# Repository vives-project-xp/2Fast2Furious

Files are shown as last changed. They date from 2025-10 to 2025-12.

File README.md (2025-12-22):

# Handgestuurde RC Wagen




> Ontwikkel een RC wagen die bestuurd wordt via handbewegingen

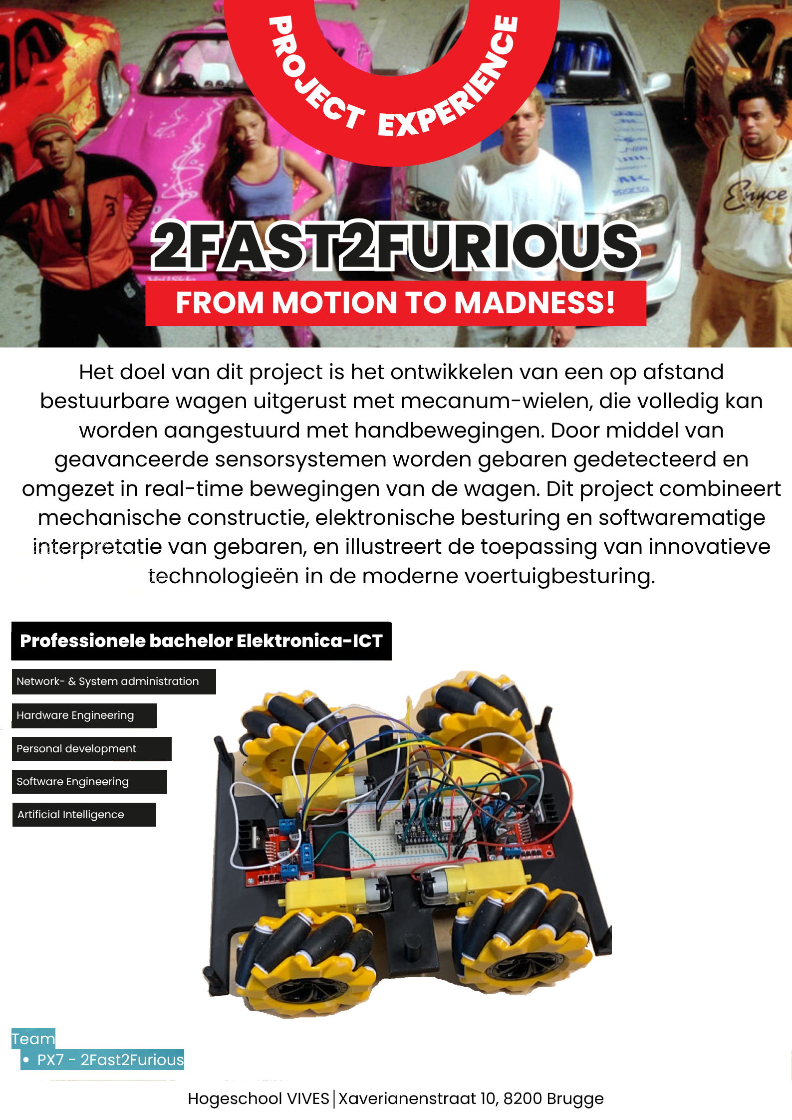
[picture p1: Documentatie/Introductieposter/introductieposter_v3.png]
Poster


## Opdracht

We ontwikkelen een RC wagen die alle richtingen uit kan rijden en bestuurd wordt via handbewegingen. De besturing van de wagen gebeurt door middel van een handcontroller die bewegingen van de hand detecteert en deze omzet in commando's voor de wagen.

## Inhoud

### Software

De software voor dit project is te vinden in de [Software](Software/README.md) map. We gebruiken Arduino C/C++ voor de ontwikkeling van de firmware voor zowel de handcontroller als de RC wagen.

### Hardware

De hardware componenten en schema's zijn te vinden in de [Hardware](Hardware/README.md) map. We maken gebruik van een microcontroller, sensoren en motoren om de RC wagen te besturen.

### Documentatie

De documentatie voor het project zijn te vinden in de [Documentatie](Documentatie/README.md) map. Hierin vind je  technische documentatie. Hierin vind je ook de uitleg over de componenten en hoe we deze hebben gebruikt in het project.

### Handleiding

De handleiding om dit project in elkaar steken en werkende te krijgen kan men vinden in de [Handleiding](Handleiding/README.md) map.

## Team

| team | Afstudeerrichting |
| ---- | --- |
| [ Sam De Wispelaere](https://github.com/SamDw123)| Software Engineering en AI |
| [ Niels Denoo](https://github.com/NielsDenoo)| Software Engineering en AI |
| [ Ewoud Bouttelisier](https://github.com/EwoudBoutje)| Software en netwerken |
| [ Maxime Coen](https://github.com/Maxime-00)| Software en netwerken |
| [ Jules Declercq](https://github.com/JulesDeclercq)| Software en netwerken |

## Planning

### Sprint 1 (week 1-4)

- [x] onderzoek naar geschikte componenten
- [x] ontwerp van de handcontroller
- [x] ontwerp van de RC wagen
- [x] testen van componenten
- [x] bestellen componenten
- [x] beginnen met code schrijven

### Sprint 2 (week 5-8)

- [x] ambassadeur van het project (poster & sociale media)
- [x] code testen en aanpassen waar nodig
- [x] in elkaar steken van de handcontroller
- [x] in elkaar steken van de RC wagen

### Sprint 3 (week 9-12)

- [X] presentatie maken
- [X] github in orde brengen
- [x] volledige tank laten rijden
- [x] ai model werkende krijgen
- [x] tank laten 'schieten' met laser transmitter
- [ ] documentatie afwerken

## Verdere uitbreidingen

- Het maken van doelwitten voor de wagon om op te schieten met het lasersysteem.

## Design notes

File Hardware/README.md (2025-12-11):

# Hardware

Deze map bevat alle hardware componenten en schema's voor het project.

## Inhoud

1. [De hardware van de auto](#de-hardware-van-de-auto)
2. [Hand Controller](#hand-controller)
3. [Tank](#tank)
3. [Target](#target)

## De hardware van de auto

### Auto

1. Arduino Nano 33 BLE Sense Rev2
2. 2x L298N motor driver
3. 4x TT-Motor
4. 7.4V Traxxas Batterij
5. Servo SG90 Micro 
6. Breadboard

### Tank gedeelte

1. Servo SG90 Micro
2. Laser Diode Transmitter

### Elektrisch schema

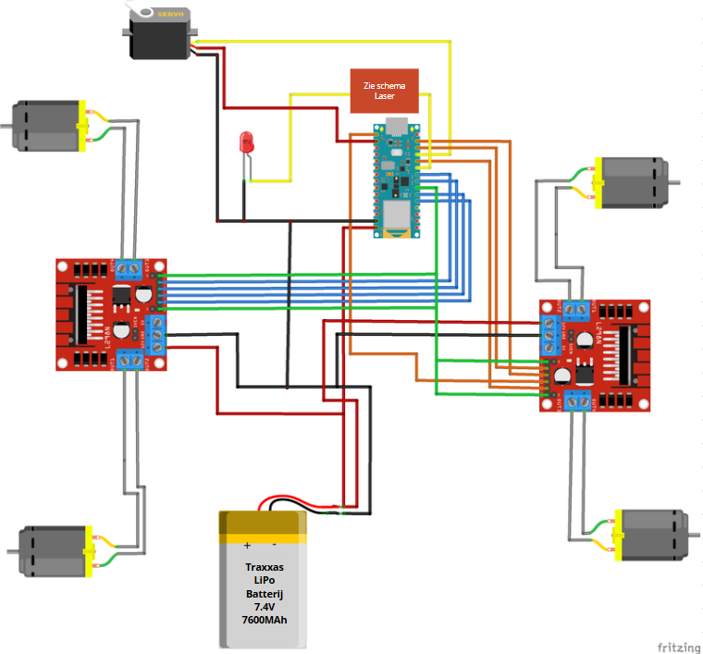
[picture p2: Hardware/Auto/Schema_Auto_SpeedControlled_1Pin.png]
schema speedcontroller


*Figuur: Elektrisch schema van de auto met Arduino Nano 33 BLE Sense REV2: Variabele snelheidsregeling*

Om bovenstaande schema na te maken moet je de twee omhulsels van de buitenste connector pinnen op de motordrivers verwijderen. Zie foto hieronder.

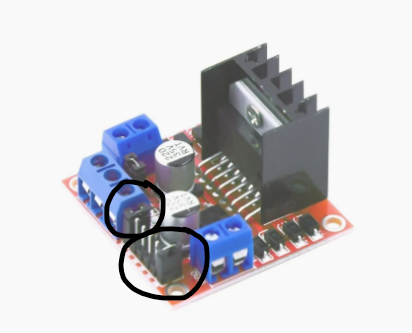
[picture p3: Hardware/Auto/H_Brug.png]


#### Variabele snelheidsregeling: 
Op het schema zijn alle motoren aangesloten op 1 snelheids regeling Pin. Dit zorgt er voor dat je alle motoren samen kunt versnellen of vertragen. Dit word bij ons gebruikt om in "tank mode" rond te draaien zodat de tank niet te snel draait en in de "car mode" om de snelhied iets te berpeken tijdens het rijden.

### Schema Laser 

Helaas stuurt de Arduino Nano 33 BLE Rev2 maar 3,3V signaalen uit en heeft de laser zelf 5V nodig. Met 3,3V is deze laser niet fel genoeg. Hiervoor moesten we nog een schakeling voorzien.

Deze schakeling bestaat uit volgende onderdelen:
1. HW-493 Laser board
2. BD135 NPN Transistor
3. 220 Ohm weerstand
4. 3xAAA batterijhouder

De drie AAA-batterijen (4,5 V) voeden de laser zodat deze feller is. De Arduino gebruikt de transistor als een digitale schakelaar om deze laser AAN en UIT te zetten.

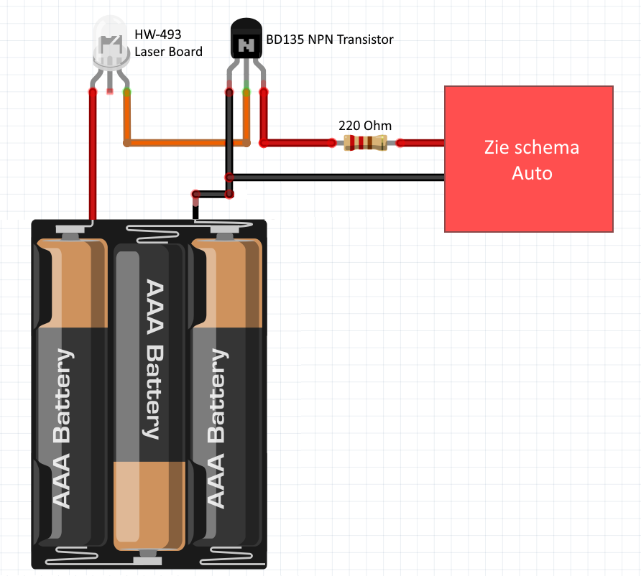
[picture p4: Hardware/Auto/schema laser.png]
schema laser


## Hand Controller

### Concept

De hand controller is de intuïtieve/immersive interface voor de besturing van de RC-car, met uitbreiding van een turret.

### Kern

De controller maakt gebruik van een Arduino Nano 33 BLE Sense Rev2. Deze microcontroller werd gekozen vanwege:

1. Inertial Measurement Unit (IMU): De interne accelerometer en gyroscoop lezen de pitch (voor/achterwaartse kanteling) en de roll (zijwaartse kanteling) data om de oriëntatie van de hand in real-time te bepalen.
2. Bluetooth Low Energy (BLE) Module: Voor draadloze communicatie met de RC-car.
3. Magic Wand/Tensorflow Gesture Recognition als uitbreiding. Laat toe te schakelen tussen verschillende modussen of functies van de controller zonder extra knoppen te monteren/de andere hand te moeten gebruiken.

### Montage

De Arduino wordt gemonteerd op een 3D-geprintte palm-bracelet dat ook de 3x AAA batterijhouder power supply huist. Zie de .stl-files voor meer info.

### Besturing

De bewegingsdata van de IMU wordt in onze software vertaald naar digitale bewegingscommando's en verzonden naar de RC-car.

| Modus | IMU Data | Commando |
| :--- | :--- | :--- |
| Car | Kantelen naar voren | Rijden vooruit |
| Car | Kantelen naar achteren | Rijden achteruit |
| Car | Kantelen naar links | Rijden links |
| Car | Kantelen naar rechts | Rijden rechts |
| Car | Kantelen naar linksvoor | Rijden linksvoor in hondengang |
| Car | Kantelen naar rechtsvoor | Rijden rechtsvoor in hondengang |
| Car | Kantelen naar linksachter | Rijden linksachter in hondengang |
| Car | Kantelen naar rechtsachter | Rijden rechtsachter in hondengang |
| Turret | Kantelen naar links | Car roteert op as links |
| Turret | Kantelen naar rechts | Car roteert op as rechts |
| Turret | Kantelen naar voren | Turret mikt hoger (servo) |
| Turret | Kantelen naar achteren | Turret mikt lager (servo) |

### Turret Modus

Aan de hand van Gesture Recognition kan de user schakelen tussen verschillende modussen.
In Turret Modus veranderd de interpretatie van de IMU-data:

Zijwaartse kanteling wordt gebruikt om de car op zijn vaste as te laten roteren, zoals in tank-besturing.
De voor- en achterwaartse kanteling wordt gebruikt om een servomotor in de turret aan te sturen. Deze servo is verantwoordelijk voor de elevatie van een gemonteerde laserdiode.

### Laserdiode

De eerdervernoemde Gesture Recognition die zorgt voor schakelen tussen de twee modussen en heeft een secundaire functie, namelijk de laserdiode aan of uit schakelen.
De 'Gesture' die men daarvoor moet doen is een 'punch' of met andere woorden een stoot geven met de vuist.
Dit voorkomt dat de laser onbedoeld aanblijft.

### Onderdelen Hand controller
1. Arduino Nano 33 BLE Sense REV2

2. 3xAAA batterijhouder

3. Bracelet behuizing en straps

#### Schema:

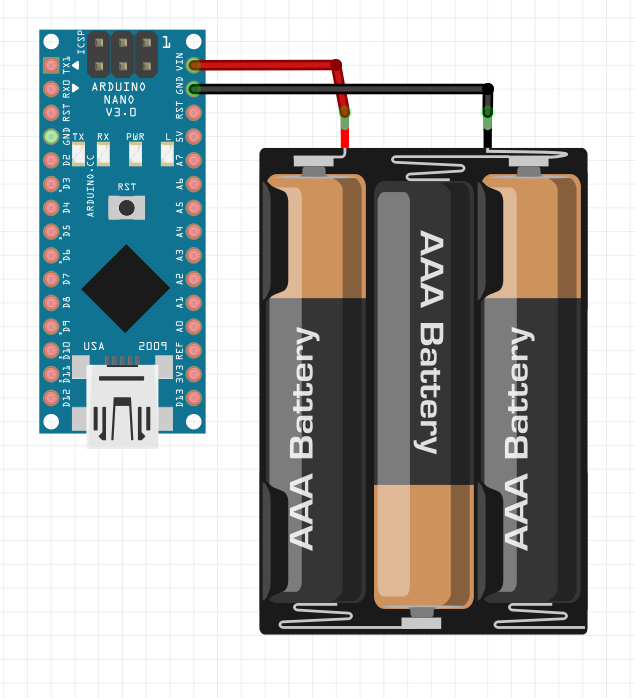
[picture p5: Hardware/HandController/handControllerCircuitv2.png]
Schema van de hand controller


### STL

Alle STL files voor het ontwerp van de handcontroller die gebruikt werden tijdens dit project zijn te vinden in deze [map](./Handschoen/STL_files/).

## Tank

### Previews

De RC tank is gemaakt uit vier verschillende onderdelen, zijnde het chassis van de tank, de carosserie, de kop en een loop. 

Het chassis is gedesigned zodat er plaats voorzien is voor de vier motoren, alsook plaats voor twee driver boards. Verder zijn er kleine pinnen voorzien op het chassis zodat de carosserie er op bevestigd kan worden.

Op de bovenkant van de carosserie is er plaats voorzien voor de servo-motor met ook een gat voor bekabeling. Daarnaast zijn er gaten aan de onderkant zodat de carosserie op het chassis past. Aan de bovenkant zijn er gaten voorzien voor het bevestigen van de kop.

In de kop is er een gat voorzien om de loop door te steken.
Ook zijn er pinnen voorzien aan de onderkant voor de montage op de carosserie.

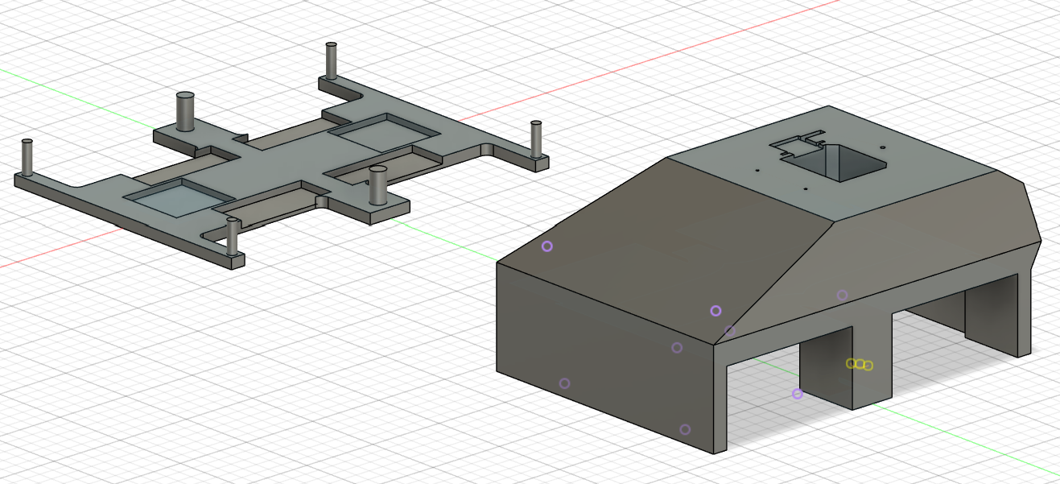
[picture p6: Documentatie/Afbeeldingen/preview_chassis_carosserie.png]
chassis

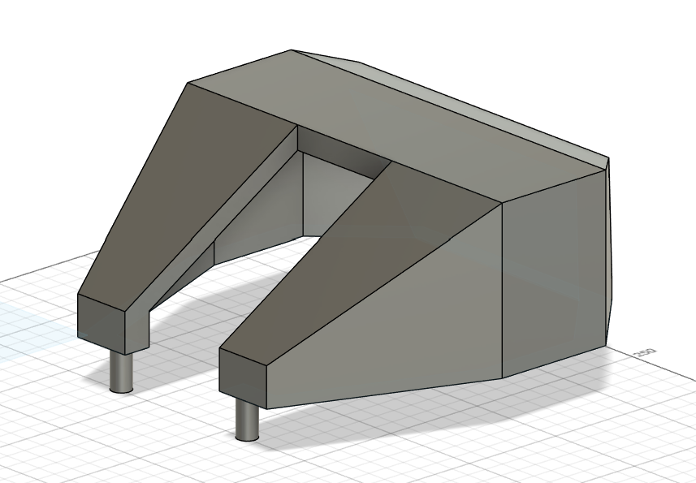
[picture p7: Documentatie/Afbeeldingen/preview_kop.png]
kop

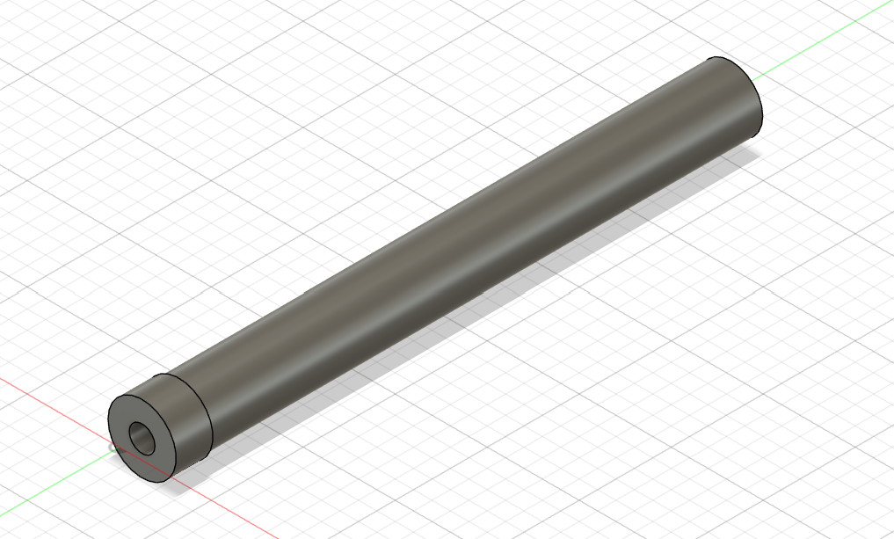
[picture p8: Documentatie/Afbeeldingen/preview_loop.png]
loop


### STL

Alle STL files voor het ontwerp van de tank die gebruikt werden tijdens dit project zijn te vinden in deze [map](./Tank/STL_files/).

⬅️ [Terug naar overzicht](../README.md#Inhoud)

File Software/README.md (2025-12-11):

# Software

In deze map bevindt zich alle **broncode** die ontwikkeld is voor dit project.

## Bestandsstructuur

De code is georganiseerd in de volgende hoofdmappen om het beheer en de testbaarheid te optimaliseren:

* **`MainCode/`**: Bevat de **volledige, definitieve broncode** voor de productieversie van de robot.
    * `SpeedControlledCar.ino`: Code voor de **robotwagen** met speed controlled auto. (geupload naar de Arduino op de auto).
    * `gesture_classifier.ino`: Code voor de **handcontroller** met gestures als **Circle** en **Punch** om van mode te switchen en te "schieten". [Voor meer info hier over klik hier](./MainCode/gestureModel/README.md) .

* **`Test Codes/`**: Bevat diverse **losse scripts** die zijn geschreven om specifieke hardware- of software-onderdelen onafhankelijk te testen, zoals de BLE-verbinding, motoraansturing of sensordata-uitlezing.

## Gebruikte Libraries

De meeste programma's maken gebruik van standaard Arduino-libraries. Hieronder vind je een overzicht van de belangrijkste:

| Library | Functie |
| :--- | :--- |
| `ArduinoBLE.h` | Voor het opzetten en beheren van de Bluetooth Low Energy (BLE) verbinding. |
| `Servo.h` | Voor het eenvoudig aansturen van de servomotor. |
| `Arduino_BMI270_BMM150.h` | Voor het uitlezen van sensor- en gyroscoopdata. |
| `Chirale_TensorFlowLite.h` | Voor de gesture classifier. |

## Uploaden & Setup

Om de code te uploaden en het project te kunnen draaien, volgt u de onderstaande stappen:

1. **Arduino IDE Installeren:** Zorg ervoor dat de nieuwste versie van de **Arduino IDE** is geïnstalleerd.
2. **Libraries Installeren:** Installeer de libraries die vermeld staan in de tabel (via **Sketch > Library's Inclusief > Library's Beheren...** in de IDE).
3. **Uploaden naar de Auto:** Open het **`SpeedControlledCar.ino`** bestand en upload deze code naar de Arduino die is gemonteerd op de **robotwagen**.
4. **Uploaden naar de Controller:** [Voor meer info hier over klik hier](./MainCode/gestureModel/README.md).

>**Tip:** Zorg ervoor dat in de Arduino IDE het juiste **Board** en de juiste **Poort** zijn geselecteerd voordat u de code uploadt.

---

⬅️ [Terug naar overzicht](../README.md#Inhoud)

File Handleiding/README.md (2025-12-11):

# Handleiding

Hier kan je een handleiding vinden voor het in elkaar steken en werkende te krijgen van de tank.

## tank bouwen

Maak eerst de tank volgens het elektrische schema in de map [hardware](../Hardware/README.md).

Elektrisch schema tank

Bevestig daarna alle onderdelen op de grondplaat van de tank. De stl files voor deze af te printen vind je in de map [hardware/tank/STL_files](../Hardware/Tank/STL_files/README.md).

## Software installeren op de tank

Op de microcontroller van de tank moet je [speedcontrolledcar.ino](../Software/MainCode/SpeedControlledCar/SpeedControlledCar.ino) uploaden. Dit kan je doen met de Arduino IDE.

Zorg dat je de juiste board en poort selecteert in de Arduino IDE voordat je upload en ook dat je de benodigde libraries hebt geïnstalleerd.
De benodigde libraries zijn:

- Servo
- ArduinoBLE

## Software installeren op de controller

Op de microcontroller van de controller moet je [gesture_classifier.ino](../Software/MainCode/handcontroller/gesture_classifier/gesture_classifier.ino) uploaden. Dit kan je doen met de Arduino IDE.
Zorg dat je de juiste board en poort selecteert in de Arduino IDE voordat je upload en ook dat je de benodigde libraries hebt geïnstalleerd.
De benodigde libraries zijn:

- ArduinoBLE
- Arduino_BMI270_BMM150
- Chirale_TensorFlowLite

Zorg er ook voor dat het model bestand `gesture_model.h` in dezelfde map staat als `gesture_classifier.ino`.

## handcontroller bouwen

Maak de handcontroller volgens het elektrische schema in de map [hardware](../Hardware/README.md).

Elektrisch schema handcontroller

Bevestig daarna alle onderdelen op de handschoen. De stl files voor deze af te printen vind je in de map [hardware/handschoen/STL_files](../Hardware/HandController/STL_files/README.md).

## model maken

Om een nieuw model te maken voor de handcontroller, volg de stappen in de map [gestureModel](../Software/MainCode/gestureModel/README.md). Daar wordt uitgelegd hoe je een nieuw model kan trainen en exporteren naar een bestand dat je kan gebruiken in de Arduino IDE.

## Verbinden en gebruiken

Zorg dat de tank en de controller beide aanstaan. De controller zal automatisch verbinding maken met de tank zodra deze binnen bereik is. De connectie kun je zien in de seriële monitor van de Arduino IDE of putty op baudrate 115200. Zodra de verbinding is gemaakt, kun je de tank besturen met gebaren en handbewegingen. Als hij geen verbinding maakt, reset de controller op de tank.

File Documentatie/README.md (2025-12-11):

# Documentation

Deze map bevat documentatie en specificaties voor het project.

## BOM

Hieronder staat de Bill of Materials (BOM) voor het project:

| Component | Prijs/stuk | Aantal | Totaalprijs | Opmerking | Link naar component |
|---|---|---|---|---|---|
| Arduino Nano 33 BLE Sense Rev2 with Headers | €44,15 | 2 | €88,30 | Microcontroller met gyroscoop en bluetooth | [kiwi](https://www.kiwi-electronics.com/en/arduino-nano-33-ble-sense-rev2-with-headers-11207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) |
| mecanum wielen (2 stuks) | €13,00 | 2 | €26,00 | Wielen voor omnidirectionele beweging | [otronic](https://www.otronic.nl/nl/mecanum-wiel-omnidirectioneel-wiel-80mm-a-geel-set.html) |
| McNamum wielkoppeling | €4,40 | 4 | €17,60 | Koppeling voor mecanum wielen | [otronic](https://www.otronic.nl/nl/67mm-mcnamum-wielkoppeling-met-m2530-schroef.html) |
| TT-motor | €2,00 | 4 | €8,00 | Motor voor aandrijving van de wielen | [otronic](https://www.otronic.nl/nl/tt-motor-voor-aandrijving-wielen-dubbele-as.html) |
| L298N motor driver | €2,60 | 2 | €5,20 | Motor driver voor het aansturen van de TT-motoren | [otronic](https://www.otronic.nl/nl/l298n-motor-driver-board-rood.html) |
| 4,5V batterij houder | €0,85 | 2 | €1,70 | Batterijhouder voor 3 AAA batterijen (4,5V) | [otronic](https://www.otronic.nl/nl/3x-aaa-batterijhouder-45v.html) |
| 7.4V Traxxas Batterij | €84,95 | 1 | €84,95 | Batterij voor de auto | [bol.com](https://www.bol.com/nl/nl/p/traxxas-lipo-accupack-7-4-v-7600-mah-aantal-cellen-2-25-c-softcase-traxxas-id/9200000058970910/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) |
| Aansluit kabel batterij | €9,95 | 1 | €9,95 | Connector kabel voor batterij | [bol.com](https://www.bol.com/nl/nl/p/laadkabel-traxxas-30cm/9300000013705973/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) |
| servomotor SG90 micro | €4,15 | 1 | €4,15 | Servomotor voor kanon op en neer | [otronic](https://www.otronic.nl/nl/servo-sg90-micro-180-graden.html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) |
| lasertransmitter | €1,20 | 1 | €1,20 | Lasertransmitter voor kanon | [otronic](https://www.otronic.nl/nl/laser-diode-5v-module-rode-laser-650nm-5mw-koperen.html) |
| laser ontvanger | €1,95 | 1 | €1,95 | Laser ontvanger voor target | [otronic](https://www.otronic.nl/nl/5v-ontvanger-module-voor-laser-diode.html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) |
| arduino nano | €6,80 | 1 | €6,80 | Microcontroller voor de target | [otronic](https://www.otronic.nl/nl/nano-v3-arduino-compatible-ch340-voorgesoldeerd.html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) |
| PLA filament | €22,99 | 2 | €45,98 | Voor het 3D printen | [bambu](https://eu.store.bambulab.com/nl/products/pla-basic-filament?id=43992830017755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) |

De totaalprijs van alle componenten is: €301,78
   
## Componenten

Hieronder wat meer informatie over de gebruikte componenten:

### Arduino Nano 33 BLE Sense Rev2 with Headers

De Arduino Nano 33 BLE Sense Rev2 is een compacte  microcontroller vergelijkbaar met de standaard Arduino Nano, maar met extra functionaliteit. De microcontroller bevat een ingebouwde gyroscoop dat we gebruiken voor de bewegingsdetectie van de handcontroller. Daarnaast heeft de microcontroller bluetooth functionaliteit waarmee we draadloos kunnen communiceren tussen de handcontroller en de auto.

### TT-motor

De TT-motor is een kleine, goedkope en efficiënte motor die vaak wordt gebruikt in robotica en kleine voertuigen. In ons project gebruiken we de TT-motoren om de mecanum wielen aan te drijven.

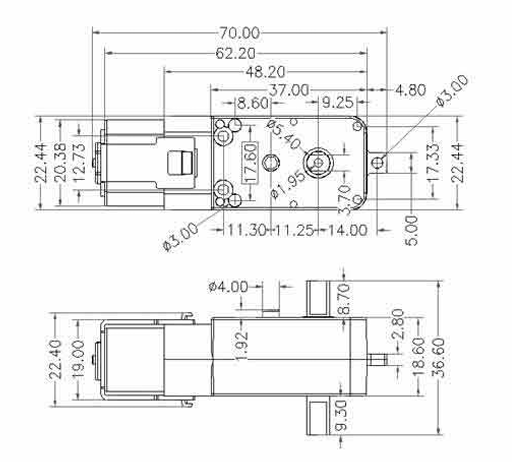
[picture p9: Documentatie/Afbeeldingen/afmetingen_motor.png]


### L298N motor driver

De L298N motor driver is een motor driver die we gebruiken om de TT-motoren aan te sturen. De motor driver kan twee DC-motoren tegelijk aansturen en kan zowel de snelheid als de draairichting van de motoren regelen.

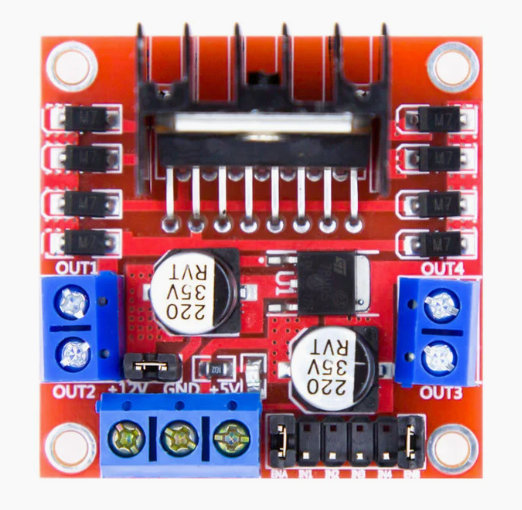
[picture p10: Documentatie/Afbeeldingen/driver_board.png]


### Mecanum wielen

Mecanum wielen zijn speciale wielen die omnidirectionele beweging mogelijk maken. Dit betekent dat het voertuig in elke richting kan bewegen zonder van richting te veranderen. Dit wordt bereikt door de unieke constructie van de wielen, die bestaan uit meerdere rollers die onder een hoek zijn geplaatst.

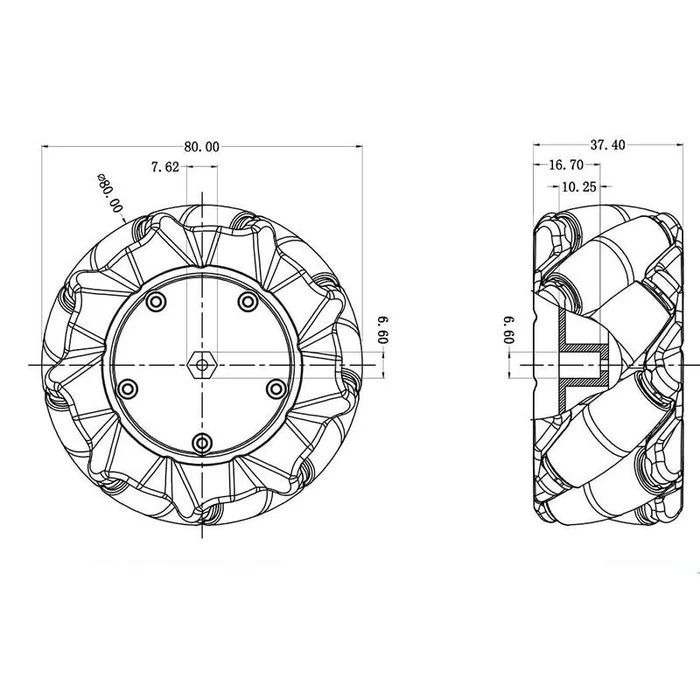
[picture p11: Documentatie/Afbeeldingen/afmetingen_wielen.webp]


### Servomotor SG90 micro

De SG90 is een kleine en lichte servomotor die vaak wordt gebruikt in modelbouw en robotica. In ons project gebruiken we de SG90 servomotor om het kanon van de auto omhoog en omlaag te bewegen.

### Lasertransmitter en ontvanger

De lasertransmitter zendt een laserstraal uit die wordt gebruikt als projectiel in ons lasershooterspel. De laser ontvanger detecteert wanneer de laserstraal wordt geraakt, wat wordt gebruikt om te bepalen of een doelwit is getroffen.

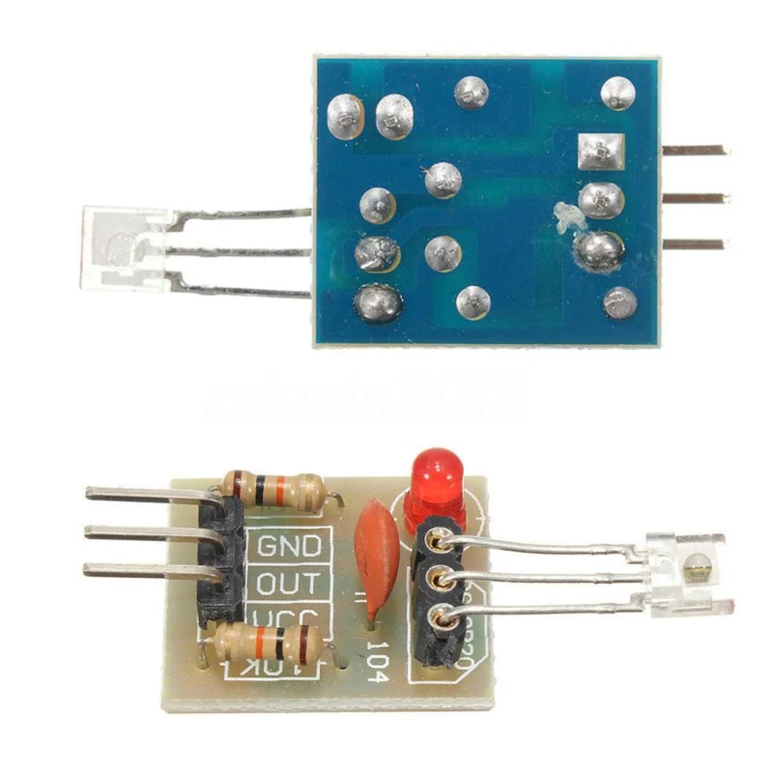
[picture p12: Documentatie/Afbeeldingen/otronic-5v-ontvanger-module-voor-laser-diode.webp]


### Arduino nano

De Arduino Nano is een kleine, veelzijdige microcontroller die we gebruiken in de target van ons lasershooterspel. Het is verantwoordelijk voor het detecteren van hits van de laserstraal en het bijhouden van de score.

## Idee kanon en target

### Kanon

Het idee dat we hebben voor het kanon is om een servomotor op de tank te plaatsen die het kanon omhoog en omlaag kan bewegen. Op het kanon is een lasertransmitter gemonteerd die een laserstraal uitzendt wanneer het kanon wordt afgevuurd. De lasertransmitter wordt aangestuurd door de Arduino Nano 33 BLE Sense Rev2 op de handcontroller en de servomotor ook. De besturing via de handcontroller zou nog steeds hetzelfde zijn maar we voegen een extra knop toe om te wisselen tussen rijden en turret modus. In turret modus kan de gebruiker het kanon omhoog en omlaag bewegen met behulp van de gyroscoop in de handcontroller, ook kan de gebruiker de tank laten draaien rond zijn eigen as. De laser gaat aan zodra de wagen in turret modus wordt geschakelt.

### Target

Het target bestaat uit een Arduino Nano die is verbonden met een laser ontvanger module. De laser ontvanger detecteert wanneer de laserstraal van het kanon het target raakt. Wanneer een hit wordt gedetecteerd, stuurt de Arduino Nano een signaal naar een LED of een buzzer om aan te geven dat het target is geraakt. Daarnaast kan de Arduino Nano ook de score bijhouden en deze weergeven op een klein LCD-scherm.

## Introductieposter

[Hier](./Introductieposter/introductieposter.md) kan je de introductieposter vinden van ons project.

## Architectuur document

Hieronder staan de architectuur documenten voor het project.

### Architectuur van de auto

Architectuur van de auto

### Architectuur van de handcontroller

Architectuur van de handcontroller  

## Prototypes

In de map [afbeeldingen](./Afbeeldingen/) kan je enkele foto's vinden van enkele prototype's. Er is een afbeelding te vinden van een amazon variant waar onze eigen rc wagen op gebaseerd is. Er zijn ook schetsen te vinden over hoe we componenten plaatsen op onze rc wagen (ook te afmetingen zijn hierop te vinden). Verder zijn er afbeeldingen te vinden genaamd 3d_tank en 3d_handcontroller, deze tonen eerdere versies van de uiteindelijke tank en handcontroller.

⬅️ [Terug naar overzicht](../README.md#Inhoud)

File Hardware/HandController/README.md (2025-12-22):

# Handcontroller

De hand controller bestaat uit twee onderdelen: fysiek en elektronica.

## Fysiek

Het fysiek onderdeel bestaat uit vijf componenten: 
- Housing bodemplaat (gehold)
- Housing bovenplaat (gehaakt)
- Housing arduino gleuf
- Pols strap (gaten)
- Pols strap (haken)

De housing-componenten kunnen worden afgeprint a.d.h.v. de .stl-files, gevonden in de submap van de huidige folder.
De pols straps zijn gerecycleerd uit de hand controller van een chinees speelgoed autotje gedoneerd door Mnr. Calleeuw.

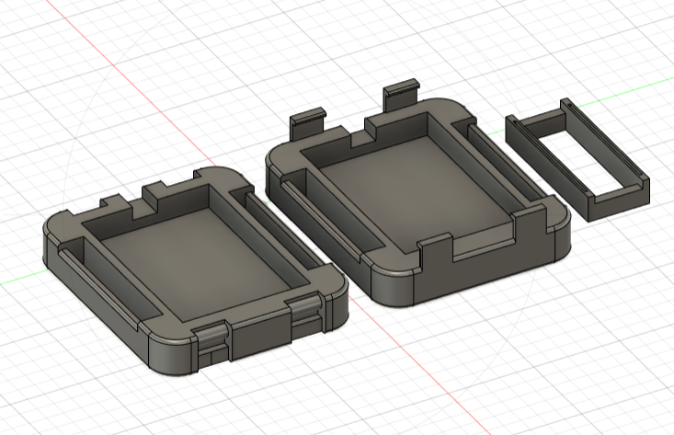
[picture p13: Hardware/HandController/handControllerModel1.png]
Hand Controller Fysieke Onderdelen


## Elektronica

Het elektronica onderdeel bestaat uit drie componenten:
- Microcontroller Arduino Nano 3.3V BLE
- 3xAAA batterijhouder (incl. 3xAAA batterijen)
- Luskoppen voor elektrische draden

## Assemblage

De binnenkant van de twee housing platen beschikken over een holte waarin de 3xAAA batterijhouder past, alsook een zijdelingse holte waardoor de bedrading van de batterijhouder kan worden gestoken om uit de housing te geraken. Bemerkt dat de bovenplaat extra plaats overhoudt in de holte voor de draden, terwijl de bodemplaat dat niet doet om de batterijhouder vanbinnen vast te houden.

> Plaats de batterijhouder met batterijen in de holte van de bodemplaat, met de bedrading door de zijdelingse holte.

Aan de lange zijdes van de platen zijn gleuven voorzien voor de koppen van de pols straps. Afhankelijk van of de gebruiker zijn of haar linker- of rechterhand wild gebruiken, kunnen deze straps omgewisseld worden.

> Plaats de koppen van de pols straps in de gleuven.

> Klik de bovenplaat vast in de bodemplaat om de batterijhouder en pols straps vast te zetten. Extra aandacht dat de bedrading niet dubbel komt te zitten.

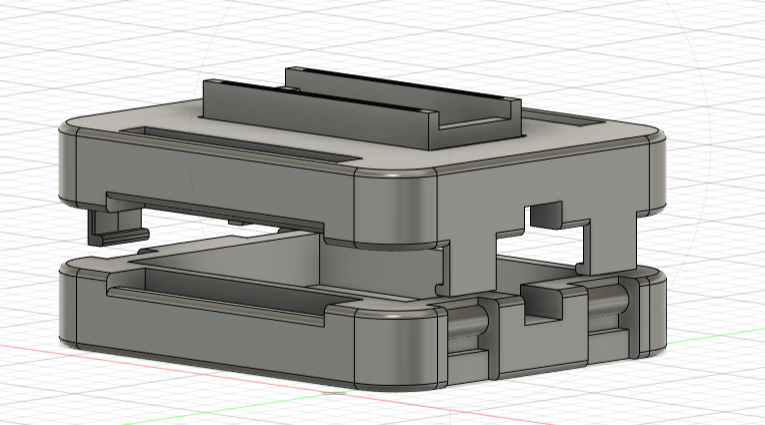
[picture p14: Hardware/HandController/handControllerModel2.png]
Hand Controller Fysieke Onderdelen


Bovenop de bovenplaat is er een holte voorzien voor de arduino gleuf.

> Plaats de arduino gleuf in de holte op de bovenplaat en zet deze vast met lijm. Extra aandacht de gleuven niet te buigen.

De luskoppen voor de bedrading dienen voor gemakkelijke vastmaking op de corresponderende pinnen op de arduino, zie hier: [Hand Controller Fysieke Onderdelen](handControllerCircuitv2.png)

> Voorzie de bedarding van luskoppen, en maak deze vast aan de juiste pinnen van de arduino.

> Schuif de arduino in de gleuf zodat de luskoppen vast komen te zitten tussen de arduino en de gleuf. Extra aandacht dat de arduino goed vastzit in de gleuf.

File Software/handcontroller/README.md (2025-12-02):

# De software van de handschoen

Deze map bevat alle software die op de Arduino Nano 33 BLE Sense Rev2 van de handschoen draait.

## Bestanden

- `gesture_classifier.ino`: Dit is het hoofdprogramma dat de sensorgegevens leest, gebarenclassificatie uitvoert en de resultaten verzendt via Bluetooth. Deze map bevindt zich in de gesture_classifier map.

## Vereisten

**Arduino Bibliotheken**:

   - `Chirale_TensorFlowLite`
   - `Arduino_BMI270_BMM150`
   - `ArduinoBLE`

**model toevoegen**
Het model `gesture_model.h` moet zich in dezelfde map bevinden als `gesture_classifier.ino`.

## Gebruik

1. Open `gesture_classifier.ino` in de Arduino IDE.
2. Zorg ervoor dat alle vereiste bibliotheken zijn geïnstalleerd.
3. Upload de code naar de Arduino Nano 33 BLE Sense Rev2.
4. Koppel de handschoen via Bluetooth aan met de ontvanger (tank). Dit zal automatisch gebeuren zodra de tank en de handschoen worden ingeschakeld.
5. Open een seriële monitor (baudrate 115200) om debug-informatie te bekijken.

## Uitleg van de code

### Overzicht
De `gesture_classifier.ino` code combineert IMU-sensordata met machine learning om handgebaren te herkennen en te classificeren. De code werkt non-blocking, wat betekent dat het geen gebruik maakt van `delay()` functies die het programma blokkeren, waardoor BLE-communicatie en andere taken soepel blijven verlopen.

### Hoofdcomponenten

#### 1. Globale Configuratie en Constanten
```cpp
const int NUM_SAMPLES = 200;      // Aantal samples per gebaar
const int NUM_AXES = 6;           // 3 accelerometer + 3 gyroscoop assen
const int NUM_FEATURES = 24;      // 4 statistieken per as (mean, std, min, max)
const int NUM_CLASSES = 3;        // Aantal gebaar-klassen
```
- **NUM_SAMPLES**: Er worden 200 datapunten verzameld voordat een gebaar wordt geclassificeerd
- **NUM_AXES**: 6 dimensies van bewegingsdata (X, Y, Z voor acceleratie en rotatie)
- **NUM_FEATURES**: Per as worden 4 statistieken berekend (gemiddelde, standaarddeviatie, minimum, maximum)
- **GESTURES[]**: Array met de namen van de gebaren: "Punch", "circle" en "idle"

#### 2. TensorFlow Lite Setup
```cpp
constexpr int kTensorArenaSize = 12 * 1024;  // 12KB voor TensorFlow
alignas(16) uint8_t tensor_arena[kTensorArenaSize];
```
De TensorFlow Lite interpreter heeft geheugen nodig om het neural network model uit te voeren. Dit wordt gereserveerd in de `tensor_arena` buffer van 12KB.

#### 3. Data Opslag en Sampling
```cpp
int16_t sample_buffer[NUM_SAMPLES][NUM_AXES];
```
De sensordata wordt opgeslagen als 16-bit integers om geheugen te besparen:
- **Acceleratie**: opgeslagen als milli-g (waarde × 1000)
- **Gyroscoop**: opgeslagen als centi-graden/sec (waarde × 100)

Dit bespaart 50% geheugen vergeleken met 32-bit floats, wat cruciaal is op een microcontroller.

#### 4. Non-Blocking Sampling State Machine
```cpp
bool samplingActive = false;
unsigned long nextSampleMs = 0;
const unsigned long sampleIntervalMs = 10;        // 10ms tussen samples
const unsigned long cycleCooldownMs = 500;        // 500ms pauze na detectie
```
De code gebruikt een state machine met tijdstempels om non-blocking te werken:
- Samples worden elke 10ms genomen (100 Hz)
- Na detectie van een gebaar volgt een cooldown van 500ms
- Dit voorkomt dat dezelfde beweging meerdere keren wordt gedetecteerd

#### 5. Preprocessing Parameters
```cpp
const float feature_mean[NUM_FEATURES] = { ... };
const float feature_std[NUM_FEATURES] = { ... };
```
Deze arrays bevatten de normalisatieparameters die tijdens het trainen van het model zijn berekend. Ze worden gebruikt om de features te standaardiseren (zero mean, unit variance), wat essentieel is voor accurate classificatie.

### Setup() Functie

De `setup()` functie initialiseert alle componenten:

1. **IMU Initialisatie**
   ```cpp
   if (!IMU.begin()) {
     Serial.println("ERROR: IMU initialization failed!");
     while (1);
   }
   ```
   Start de BMI270/BMM150 sensor en controleert of deze correct werkt.

2. **BLE Setup**
   ```cpp
   BLE.setLocalName("NanoClassifier");
   BLE.setAdvertisedService(controlService);
   ```
   Configureert Bluetooth Low Energy met de naam "NanoClassifier" en maakt een service aan met UUID `12345678-1234-5678-1234-56789abcdef0`.

3. **TensorFlow Lite Model Laden**
   ```cpp
   model = tflite::GetModel(gesture_model);
   static tflite::MicroInterpreter static_interpreter(...);
   ```
   Laadt het getrainde model uit `gesture_model.h` en initialiseert de TensorFlow Lite interpreter.

### Loop() Functie - Hoofdlogica

De `loop()` functie doorloopt continu verschillende fases:

#### Fase 1: BLE Polling en Connectie Management
```cpp
BLE.poll();
if (BLE.connected() && !deviceConnected) {
  Serial.println("BLE connected");
  deviceConnected = true;
}
```
Houdt de BLE-verbinding actief en detecteert wanneer een apparaat verbindt/disconnecteert.

#### Fase 2: Start van Sampling Cyclus
```cpp
if (!samplingActive && now >= nextCycleMs) {
  samplingActive = true;
  samples_read = 0;
  nextSampleMs = now;
}
```
Start een nieuwe sampling cyclus wanneer:
- Er momenteel geen sampling actief is
- De cooldown periode is verlopen

#### Fase 3: Data Acquisitie
```cpp
if (samplingActive && now >= nextSampleMs) {
  if (IMU.accelerationAvailable()) {
    IMU.readAcceleration(aX, aY, aZ);
    IMU.readGyroscope(gX, gY, gZ);
    
    // Opslaan in buffer als int16_t
    sample_buffer[samples_read][0] = (int16_t)(aX * 1000.0f);
    // ... etc voor andere assen
  }
}
```
Leest IMU-data wanneer beschikbaar en slaat deze compact op in de sample buffer.

#### Fase 4: Realtime Bewegingscommando's
```cpp
if ((samples_read % LOG_INTERVAL) == 0 && lastDetectedIsIdle) {
  String cmd = getCommand(xi, yi);
  Serial.println(cmd);
  commandCharacteristic.writeValue(cmd);
}
```
Tijdens het verzamelen van samples worden bewegingsrichtingen berekend op basis van de acceleratiedata:
- **F**: Forward (vooruit)
- **B**: Backward (achteruit)
- **L**: Left (links)
- **R**: Right (rechts)
- **FL, FR, BL, BR**: Diagonale richtingen
- **S**: Stop (stilstand)

Deze commando's worden alleen verstuurd wanneer het laatste gedetecteerde gebaar "idle" was, om interferentie met gebaar-detectie te voorkomen.

#### Fase 5: Feature Extraction
```cpp
void extractFeatures(float features[NUM_FEATURES]) {
  for (int axis = 0; axis < NUM_AXES; axis++) {
    // Bereken mean, std, min, max voor elke as
    float mean = sum / NUM_SAMPLES;
    float std_dev = sqrt(variance);
    features[base_idx + 0] = mean;
    features[base_idx + 1] = std_dev;
    features[base_idx + 2] = min_val;
    features[base_idx + 3] = max_val;
  }
}
```
Voor elke van de 6 assen worden 4 statistische kenmerken berekend:
- **Gemiddelde**: centrale tendentie van de beweging
- **Standaarddeviatie**: variabiliteit/intensiteit van de beweging
- **Minimum**: extreme waarde in negatieve richting
- **Maximum**: extreme waarde in positieve richting

Dit resulteert in 24 features (6 assen × 4 statistieken).

#### Fase 6: Feature Normalisatie
```cpp
void normalizeFeatures(float features[NUM_FEATURES]) {
  for (int i = 0; i < NUM_FEATURES; i++) {
    features[i] = (features[i] - feature_mean[i]) / feature_std[i];
  }
}
```
Standaardiseert alle features naar gemiddelde 0 en standaarddeviatie 1. Dit is cruciaal omdat:
- Het neural network verwacht genormaliseerde input
- Het voorkomt dat features met grotere waarden domineren
- Het verbetert de trainingssnelheid en nauwkeurigheid

#### Fase 7: Neural Network Inferentie
```cpp
for (int i = 0; i < NUM_FEATURES; i++) {
  input->data.f[i] = features[i];
}
interpreter->Invoke();
```
De genormaliseerde features worden naar de input tensor van het model gekopieerd, waarna `Invoke()` het neural network uitvoert en voorspellingen genereert.

#### Fase 8: Classificatie en Output
```cpp
float max_score = output->data.f[0];
int max_index = 0;
for (int i = 1; i < NUM_CLASSES; i++) {
  if (output->data.f[i] > max_score) {
    max_score = output->data.f[i];
    max_index = i;
  }
}
```
Het model output bevat een confidence score voor elke klasse. De klasse met de hoogste score wordt geselecteerd:
- **Index 0 (Punch)**: Stuurt commando "P"
- **Index 1 (Circle)**: Stuurt commando "C"
- **Index 2 (Idle)**: Geen speciale actie, activeert bewegingscommando's

#### Fase 9: Cooldown en State Reset
```cpp
samples_read = 0;
samplingActive = false;
lastDetectedIsIdle = (max_index == 2);
nextCycleMs = millis() + cycleCooldownMs;
```
Na classificatie wordt de state gereset en begint een cooldown periode van 500ms voordat de volgende detectiecyclus start.

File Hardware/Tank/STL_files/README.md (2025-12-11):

# STL files tank

In deze map kan je de STL files vinden om de onderdelen van de tank te 3D printen.

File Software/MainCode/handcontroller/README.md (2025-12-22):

# De software van de handschoen

Deze map bevat alle software die op de Arduino Nano 33 BLE Sense Rev2 van de handschoen draait.

## Bestanden

- `gesture_classifier.ino`: Dit is het hoofdprogramma dat de sensorgegevens leest, gebarenclassificatie uitvoert en de resultaten verzendt via Bluetooth. Deze map bevindt zich in de gesture_classifier map.
- gesture_model.h: Dit bestand bevat het getrainde TensorFlow Lite model dat wordt gebruikt voor gebarenherkenning. Dit bestand moet worden gegenereerd door het trainingsproces en in dezelfde map als `gesture_classifier.ino` worden geplaatst. Het trainen bevindt zich in de [gesture_classifier](../gesture_classifier/README.md) map.

## Vereisten

**Arduino Bibliotheken**:

- `Chirale_TensorFlowLite`
- `Arduino_BMI270_BMM150`
- `ArduinoBLE`

**Model**
Het model `gesture_model.h` moet zich in dezelfde map bevinden als `gesture_classifier.ino`.

## Gebruik

1. je maakt een .venv aan:

```bash
python -m venv .venv
.venv\Scripts\activate   
# Op Linux gebruik je: source .venv/bin/activate
```

2. Installeer de benodigde packages:

```bash
pip install -r requirements.txt
```

3. Installeer arduino libraries in arduino IDE of via Arduino CLI:

    **Arduino IDE**:
    Installeer volgende libraries in de Arduino IDE via Library Manager (Sketch -> Include Library -> Manage Libraries...):

    - Arduino_BMI270_BMM150
    - Chirale_TensorFlowLite

    **Arduino CLI**:

   - Download Arduino CLI van [arduino.cc/en/software](https://arduino.cc/en/software) of installeer via package manager indien je deze niet hebt:

   ```bash
   # Windows (via winget)
   winget install ArduinoSA.CLI

   # Windows (via chocolatey)
   choco install arduino-cli

   # macOS
   brew install arduino-cli

   # Linux
   curl -fsSL https://raw.githubusercontent.com/arduino/arduino-cli/master/install.sh | sh
   ```

   - Installeer de benodigde boards en libraries:

   ```bash
   arduino-cli core update-index
   arduino-cli core install arduino:mbed_nano
   arduino-cli lib install "Arduino_BMI270_BMM150"
   arduino-cli lib install "Chirale_TensorFlowLite"
   ```

4. Compile en flash de Arduino code `gesture_classifier.ino` naar je microcontroller met behulp van de Arduino IDE of Arduino CLI.

```bash
cd handcontroller/gesture_classifier
arduino-cli compile --fqbn arduino:mbed_nano:nano33ble gesture_classifier
arduino-cli upload -p <COM PORT> --fqbn arduino:mbed_nano:nano33ble gesture_classifier
```

vervang `<COM PORT>` door de juiste seriële poort van je microcontroller.

5. Controleer of het werkt door de seriële monitor te openen in de Arduino IDE of met andere seriële terminal software zoals putty:

```bash
arduino-cli monitor -p <COM PORT> --fqbn arduino:mbed_nano:nano33ble
```

Verander `<COM PORT>` naar de juiste seriële poort van je microcontroller.

## Uitleg van de code

### Overzicht

De `gesture_classifier.ino` code combineert IMU-sensordata met machine learning om handgebaren te herkennen en te classificeren. De code werkt non-blocking, wat betekent dat het geen gebruik maakt van `delay()` functies die het programma blokkeren, waardoor BLE-communicatie en andere taken soepel blijven verlopen.

### Hoofdcomponenten

#### 1. Globale Configuratie en Constanten

```cpp
const int NUM_SAMPLES = 200;      // Aantal samples per gebaar
const int NUM_AXES = 6;           // 3 accelerometer + 3 gyroscoop assen
const int NUM_FEATURES = 24;      // 4 statistieken per as (mean, std, min, max)
const int NUM_CLASSES = 3;        // Aantal gebaar-klassen
```

- **NUM_SAMPLES**: Er worden 200 datapunten verzameld voordat een gebaar wordt geclassificeerd
- **NUM_AXES**: 6 dimensies van bewegingsdata (X, Y, Z voor acceleratie en rotatie)
- **NUM_FEATURES**: Per as worden 4 statistieken berekend (gemiddelde, standaarddeviatie, minimum, maximum)
- **GESTURES[]**: Array met de namen van de gebaren: "Punch", "circle" en "idle"

#### 2. TensorFlow Lite Setup

```cpp
constexpr int kTensorArenaSize = 12 * 1024;  // 12KB voor TensorFlow
alignas(16) uint8_t tensor_arena[kTensorArenaSize];
```

De TensorFlow Lite interpreter heeft geheugen nodig om het neural network model uit te voeren. Dit wordt gereserveerd in de `tensor_arena` buffer van 12KB.

#### 3. Data Opslag en Sampling

```cpp
int16_t sample_buffer[NUM_SAMPLES][NUM_AXES];
```

De sensordata wordt opgeslagen als 16-bit integers om geheugen te besparen:

- **Acceleratie**: opgeslagen als milli-g (waarde × 1000)
- **Gyroscoop**: opgeslagen als centi-graden/sec (waarde × 100)

Dit bespaart 50% geheugen vergeleken met 32-bit floats, wat cruciaal is op een microcontroller.

#### 4. Non-Blocking Sampling State Machine

```cpp
bool samplingActive = false;
unsigned long nextSampleMs = 0;
const unsigned long sampleIntervalMs = 10;        // 10ms tussen samples
const unsigned long cycleCooldownMs = 500;        // 500ms pauze na detectie
```

De code gebruikt een state machine met tijdstempels om non-blocking te werken:

- Samples worden elke 10ms genomen (100 Hz)
- Na detectie van een gebaar volgt een cooldown van 500ms
- Dit voorkomt dat dezelfde beweging meerdere keren wordt gedetecteerd

#### 5. Preprocessing Parameters

```cpp
const float feature_mean[NUM_FEATURES] = { ... };
const float feature_std[NUM_FEATURES] = { ... };
```

Deze arrays bevatten de normalisatieparameters die tijdens het trainen van het model zijn berekend. Ze worden gebruikt om de features te standaardiseren (zero mean, unit variance), wat essentieel is voor accurate classificatie.

### Setup() Functie

De `setup()` functie initialiseert alle componenten:

1. **IMU Initialisatie**

   ```cpp
   if (!IMU.begin()) {
     Serial.println("ERROR: IMU initialization failed!");
     while (1);
   }
   ```

  Start de BMI270/BMM150 sensor en controleert of deze correct werkt.

2. **BLE Setup**

   ```cpp
   BLE.setLocalName("NanoClassifier");
   BLE.setAdvertisedService(controlService);
   ```

   Configureert Bluetooth Low Energy met de naam "NanoClassifier" en maakt een service aan met UUID `12345678-1234-5678-1234-56789abcdef0`.

3. **TensorFlow Lite Model Laden**

   ```cpp
   model = tflite::GetModel(gesture_model);
   static tflite::MicroInterpreter static_interpreter(...);
   ```

   Laadt het getrainde model uit `gesture_model.h` en initialiseert de TensorFlow Lite interpreter.

### Loop() Functie - Hoofdlogica

De `loop()` functie doorloopt continu verschillende fases:

#### Fase 1: BLE Polling en Connectie Management

```cpp
BLE.poll();
if (BLE.connected() && !deviceConnected) {
  Serial.println("BLE connected");
  deviceConnected = true;
}
```

Houdt de BLE-verbinding actief en detecteert wanneer een apparaat verbindt/disconnecteert.

#### Fase 2: Start van Sampling Cyclus

```cpp
if (!samplingActive && now >= nextCycleMs) {
  samplingActive = true;
  samples_read = 0;
  nextSampleMs = now;
}
```

Start een nieuwe sampling cyclus wanneer:

- Er momenteel geen sampling actief is
- De cooldown periode is verlopen

#### Fase 3: Data Acquisitie

```cpp
if (samplingActive && now >= nextSampleMs) {
  if (IMU.accelerationAvailable()) {
    IMU.readAcceleration(aX, aY, aZ);
    IMU.readGyroscope(gX, gY, gZ);
    
    // Opslaan in buffer als int16_t
    sample_buffer[samples_read][0] = (int16_t)(aX * 1000.0f);
    // ... etc voor andere assen
  }
}
```

Leest IMU-data wanneer beschikbaar en slaat deze compact op in de sample buffer.

#### Fase 4: Realtime Bewegingscommando's

```cpp
if ((samples_read % LOG_INTERVAL) == 0 && lastDetectedIsIdle) {
  String cmd = getCommand(xi, yi);
  Serial.println(cmd);
  commandCharacteristic.writeValue(cmd);
}
```

Tijdens het verzamelen van samples worden bewegingsrichtingen berekend op basis van de acceleratiedata:

- **F**: Forward (vooruit)
- **B**: Backward (achteruit)
- **L**: Left (links)
- **R**: Right (rechts)
- **FL, FR, BL, BR**: Diagonale richtingen
- **S**: Stop (stilstand)

Deze commando's worden alleen verstuurd wanneer het laatste gedetecteerde gebaar "idle" was, om interferentie met gebaar-detectie te voorkomen.

#### Fase 5: Feature Extraction

```cpp
void extractFeatures(float features[NUM_FEATURES]) {
  for (int axis = 0; axis < NUM_AXES; axis++) {
    // Bereken mean, std, min, max voor elke as
    float mean = sum / NUM_SAMPLES;
    float std_dev = sqrt(variance);
    features[base_idx + 0] = mean;
    features[base_idx + 1] = std_dev;
    features[base_idx + 2] = min_val;
    features[base_idx + 3] = max_val;
  }
}
```

Voor elke van de 6 assen worden 4 statistische kenmerken berekend:

- **Gemiddelde**: centrale tendentie van de beweging
- **Standaarddeviatie**: variabiliteit/intensiteit van de beweging
- **Minimum**: extreme waarde in negatieve richting
- **Maximum**: extreme waarde in positieve richting

Dit resulteert in 24 features (6 assen × 4 statistieken).

#### Fase 6: Feature Normalisatie

```cpp
void normalizeFeatures(float features[NUM_FEATURES]) {
  for (int i = 0; i < NUM_FEATURES; i++) {
    features[i] = (features[i] - feature_mean[i]) / feature_std[i];
  }
}
```

Standaardiseert alle features naar gemiddelde 0 en standaarddeviatie 1. Dit is cruciaal omdat:

- Het neural network verwacht genormaliseerde input
- Het voorkomt dat features met grotere waarden domineren
- Het verbetert de trainingssnelheid en nauwkeurigheid

#### Fase 7: Neural Network Inferentie

```cpp
for (int i = 0; i < NUM_FEATURES; i++) {
  input->data.f[i] = features[i];
}
interpreter->Invoke();
```

De genormaliseerde features worden naar de input tensor van het model gekopieerd, waarna `Invoke()` het neural network uitvoert en voorspellingen genereert.

#### Fase 8: Classificatie en Output

```cpp
float max_score = output->data.f[0];
int max_index = 0;
for (int i = 1; i < NUM_CLASSES; i++) {
  if (output->data.f[i] > max_score) {
    max_score = output->data.f[i];
    max_index = i;
  }
}
```

Het model output bevat een confidence score voor elke klasse. De klasse met de hoogste score wordt geselecteerd:

- **Index 0 (Punch)**: Stuurt commando "P"
- **Index 1 (Circle)**: Stuurt commando "C"
- **Index 2 (Idle)**: Geen speciale actie, activeert bewegingscommando's

#### Fase 9: Cooldown en State Reset

```cpp
samples_read = 0;
samplingActive = false;
lastDetectedIsIdle = (max_index == 2);
nextCycleMs = millis() + cycleCooldownMs;
```

Na classificatie wordt de state gereset en begint een cooldown periode van 500ms voordat de volgende detectiecyclus start.

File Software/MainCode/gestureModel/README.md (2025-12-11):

# gesture_classifier model

In deze folder zit de gesture_classifier model die gebruikt wordt in de software voor het classificeren van handgebaren waaronder punch en circle. Deze handgebaren worden gebruikt om de tank bepaalde acties te laten uitvoeren. Punch voor het schieten van het kannon en circle voor het veranderen van modus om het kannon te richten of de tank te laten rijden.

## Inhoud van de folder

de belangrijkste bestanden in deze folder zijn:

- [convert_cbor_to_csv.py](convert_cbor_to_csv.py): Script om de CBOR data van de handgebaren om te zetten naar CSV formaat.
- [train_tflite_model.py](train_tflite_model.py): Script om het TensorFlow Lite model te trainen met de CSV data.
- [gesture_classifier.ino](gesture_classifier.ino): Arduino code om het getrainde model te implementeren op een microcontroller. Deze bevindt zich in de [gesture_classifier](./gesture_classifier/gesture_classifier.ino) map van de handcontroller software.

Dit zijn allemaal codebestanden die gebruikt worden om het model te maken en te implementeren. Daarnaast zijn er ook enkele gegenereerde bestanden:

- `dataset.csv`: De gegenereerde dataset in CSV formaat na het uitvoeren van `convert_cbor_to_csv.py`. Gebruikt als input voor het trainingsscript.
- `gesture_model.tflite`: Het getrainde TensorFlow Lite model na het uitvoeren van `train_tflite_model.py`.
- `gesture_model.h`: C header file met het model als byte array voor gebruik in Arduino

Deze bestanden worden automatisch gegenereerd door de scripts en hoeven niet handmatig te worden aangepast.

De gesture-classifier-export map bevat de ruwe data die verzameld is via Edge Impulse. Deze data wordt gebruikt als input voor het conversie script. Deze map is niet in de git repository opgenomen vanwege de grootte van de bestanden. Deze map kan je zelf aanmaken door data te verzamelen via Edge Impulse zoals beschreven in de sectie "Hoe model maken" verderop in deze README.

## Hoe model maken

Om de gesture_classifier model te maken heb ik volgende stappen gevolgd:

### 1. Data verzamelen via Edge Impulse

Data van handgebaren werd verzameld met behulp van een microcontroller en Edge Impulse platform:

- Ga naar [Edge Impulse](https://edgeimpulse.com) en maak een nieuw project aan
- Verbind je Arduino Nano 33 BLE Sense Rev2 met Edge Impulse via de Data Forwarder of Edge Impulse CLI
- Maak labels aan voor elk gebaar (bijvoorbeeld "punch", "circle", "idle")
- Verzamel meerdere samples per gebaar (minimaal 30-50 per klasse, meer is beter)
  - Voer elk gebaar meerdere keren uit met verschillende snelheden en orientaties
  - Zorg voor consistentie in de duur van elk gebaar (bijvoorbeeld 2 seconden)
- Splits je data automatisch of handmatig in training (80%) en testing (20%) sets

### 2. Data exporteren uit Edge Impulse

Nadat je genoeg data hebt verzameld (30 tot 50 per gebaar), exporteer je de dataset:

- In Edge Impulse Studio ga naar "Dashboard" of "Data acquisition"
- Klik op het export icoon of gebruik het menu om "Export" te selecteren
- Kies voor "Export as raw features" of de ingestion data optie
- Download de ZIP file en pak deze uit

De uitgepakte folder structuur moet er als volgt uitzien:

```folder
gesture-classifier-export/
├── info.labels                          # JSON file met label mapping
├── training/                            # Training data
│   ├── circle.69md0drd.ingestion-...cbor
│   ├── circle.69md0nfj.ingestion-...cbor
│   ├── punch.69me1abc.ingestion-...cbor
│   ├── punch.69me2def.ingestion-...cbor
│   └── ...
└── testing/                             # Testing data
    ├── circle.69me5pve.ingestion-...cbor
    ├── punch.69me6ov4.ingestion-...cbor
    └── ...
```

Het `info.labels` bestand bevat de mapping tussen bestandsnamen en labels:

```json
{
  "version": 1,
  "files": [
    {
      "name": "circle.69md0drd",
      "label": {
        "type": "label",
        "label": "circle"
      }
    },
    {
      "name": "punch.69me1abc",
      "label": {
        "type": "label",
        "label": "punch"
      }
    }
  ]
}
```

### 3. Data omzetten naar CSV

We kunnen de CBOR bestanden niet direct gebruiken om het model te trainen, dus moeten we ze eerst omzetten naar een CSV bestand.
Gebruik het `convert_cbor_to_csv.py` script om de CBOR bestanden om te zetten naar een CSV bestand:

```bash
python convert_cbor_to_csv.py
```

Het script:

- Leest automatisch de `gesture-classifier-export/` folder
- Gebruikt `info.labels` om de juiste labels toe te wijzen
- Converteert alle CBOR bestanden naar een enkele `dataset.csv`
- De CSV bevat kolommen: `axis0`, `axis1`, ..., `axis5` (voor 6-axis IMU data), `label`, `filename`, `timestep`, `split`

Controleer de output:

```bash
✅ Saved dataset.csv with shape: (15234, 10)
```

### 4. Model trainen

Train het TensorFlow Lite model met het `train_tflite_model.py` script:

```bash
python train_tflite_model.py
```

Het training proces:

- Laadt `dataset.csv` en extraheert statistische features (mean, std, min, max) per opname
- Normaliseert de data en slaat normalisatie parameters op in `model_params.npz`
- Bouwt een neuraal netwerk (input → 32 neurons → 16 neurons → output classes)
- Traint gedurende 50 epochs met een 80/20 train/test split
- Converteert het model naar TensorFlow Lite formaat met optimalisaties
- Genereert een C header file voor Arduino

Output bestanden:

- `gesture_model.tflite` - TensorFlow Lite model (voor Python inferentie of debugging)
- `gesture_model.h` - C header met model als byte array (voor Arduino)
- `labels.json` - Label mapping (bijvoorbeeld `["circle", "punch"]`)
- `model_params.npz` - Normalisatie parameters (mean, std)

Voorbeeld training output:

```bash
Epoch 50/50
12/12 [==============================] - 0s 2ms/step - loss: 0.0234 - accuracy: 0.9896 - val_loss: 0.1123 - val_accuracy: 0.9583

Test Accuracy: 0.9500
✅ Saved gesture_model.tflite
✅ Saved gesture_model.h
```

### 5. Model implementeren op microcontroller

Kopieer de gegenereerde bestanden naar je Arduino project:

- `gesture_model.h` → include in je Arduino sketch
- `labels.json` → (optioneel) om label namen te tonen in plaats van indices
- `model_params.npz` → bevat normalisatie parameters (deze moet je handmatig in code hardcoden)

Implementeer de code in `gesture_classifier.ino`:

- Laad het model uit `gesture_model.h`
- Verzamel IMU data in een window buffer
- Bereken dezelfde statistische features als tijdens training
- Normaliseer met dezelfde mean/std waarden
- Voer inferentie uit en selecteer het gebaar met hoogste waarschijnlijkheid
- Voer acties uit op basis van het gedetecteerde gebaar

## Testen van het model

Om het model te testen kun je volgende stappen volgen:

1. je maakt een .venv aan:

```bash
python -m venv .venv
.venv\Scripts\activate   
# Op Linux gebruik je: source .venv/bin/activate
```

2. Installeer de benodigde packages:

```bash
pip install -r requirements.txt
```

3. Installeer arduino libraries in arduino IDE of via Arduino CLI:

    **Arduino IDE**:
    Installeer volgende libraries in de Arduino IDE via Library Manager (Sketch -> Include Library -> Manage Libraries...):

    - Arduino_BMI270_BMM150
    - Chirale_TensorFlowLite

    **Arduino CLI**:

   - Download Arduino CLI van [arduino.cc/en/software](https://arduino.cc/en/software) of installeer via package manager indien je deze niet hebt:

   ```bash
   # Windows (via winget)
   winget install ArduinoSA.CLI

   # Windows (via chocolatey)
   choco install arduino-cli

   # macOS
   brew install arduino-cli

   # Linux
   curl -fsSL https://raw.githubusercontent.com/arduino/arduino-cli/master/install.sh | sh
   ```

   - Installeer de benodigde boards en libraries:

   ```bash
   arduino-cli core update-index
   arduino-cli core install arduino:mbed_nano
   arduino-cli lib install "Arduino_BMI270_BMM150"
   arduino-cli lib install "Chirale_TensorFlowLite"
   ```

4. Compile en flash de Arduino code `gesture_classifier.ino` naar je microcontroller met behulp van de Arduino IDE of Arduino CLI.

```bash
cd gesture_classifier
arduino-cli compile --fqbn arduino:mbed_nano:nano33ble gesture_classifier
arduino-cli upload -p <COM PORT> --fqbn arduino:mbed_nano:nano33ble gesture_classifier
```

vervang `<COM PORT>` door de juiste seriële poort van je microcontroller.

5. Controleer of het werkt door de seriële monitor te openen in de Arduino IDE of met andere seriële terminal software zoals putty:

```bash
arduino-cli monitor -p <COM PORT> --fqbn arduino:mbed_nano:nano33ble
```

Verander `<COM PORT>` naar de juiste seriële poort van je microcontroller.

### Tips voor betere resultaten

- **Meer data**: Verzamel minimaal 30-50 samples per gebaar voor goede generalisatie, meer is beter
- **Data variatie**: Voer gebaren uit met verschillende snelheden, hoeken en startposities
- **Balanced dataset**: Zorg dat elke klasse ongeveer evenveel samples heeft
- **Idle klasse**: Voeg een "idle" of "unknown" klasse toe voor wanneer geen gebaar wordt uitgevoerd
- **Threshold tuning**: Experimenteer met confidence thresholds (bijv. alleen accepteren als >70% zeker)
- **Real-time testing**: Test het model op de microcontroller met nieuwe gebaren die niet in de training set zaten

## Gebruikte hardware

- microcontroller (arduino nano 33 ble sense rev2)
- IMU sensor (ingebouwd in de microcontroller)

## uitleg code

### convert_cbor_to_csv.py

Dit script leest CBOR bestanden in uit een opgegeven map, converteert de gegevens naar CSV-formaat en slaat ze op in een nieuwe map. Het script maakt gebruik van de `cbor2` bibliotheek om de CBOR-bestanden te decoderen en `pandas` om de gegevens naar CSV te schrijven. Hieruit verkrijg je [dataset.csv](dataset.csv) bestand die gebruikt wordt om het model te trainen.

**Belangrijkste delen van de code:**

- **Label mapping laden**: Het script leest eerst `info.labels` om te bepalen welk label (bv. "circle" of "punch") bij elk bestand hoort. Dit gebeurt door het JSON-bestand te parsen en een dictionary `label_map` aan te maken die bestandsnamen koppelt aan hun labels.

- **CBOR-bestanden inlezen**: Voor elke `.cbor` file in de `training/` en `testing/` mappen wordt het binaire bestand gedecoded met `cbor2.load()`. De functie `find_sensor_matrix()` zoekt recursief door de geneste structuur om de eigenlijke sensor data matrix te vinden (een lijst van lijsten met numerieke waarden).

- **Data flatten en uitbreiden**: Elk tijdstip (timestep) in de sensor matrix wordt omgezet naar een aparte rij in de dataset. Elke rij bevat kolommen voor de verschillende assen (`axis0`, `axis1`, ..., typisch 6 assen voor accelerometer + gyroscoop), plus metadata kolommen (`label`, `filename`, `timestep`, `split`).

- **CSV output**: Alle rijen worden gecombineerd in een Pandas DataFrame en opgeslagen als `dataset.csv`. Dit bestand is gestructureerd en klaar om gebruikt te worden voor machine learning training.

### train_tflite_model.py

Dit script traint een TensorFlow Lite model voor het classificeren van handgebaren op basis van de CSV-gegevens. Het script laadt de gegevens, splitst ze in trainings- en testsets, bouwt een neuraal netwerkmodel, traint het model en slaat het getrainde model op als een TFLite-bestand.

**Belangrijkste delen van de code:**

- **Feature extraction**: In plaats van raw sensor data direct te gebruiken, aggregeert het script per opname (`filename`) statistische kenmerken: voor elke as wordt het gemiddelde, standaarddeviatie, minimum en maximum berekend. Dit reduceert tijdreeksen van variabele lengte naar een vaste vector van features per gebaar.

- **Data preprocessing**: De feature vectors worden genormaliseerd door het gemiddelde af te trekken en te delen door de standaarddeviatie (`X_norm = (X - mean) / std`). Deze preprocessing-parameters (`mean` en `std`) worden opgeslagen in `model_params.npz` zodat dezelfde normalisatie later op de microcontroller kan worden toegepast.

- **Model architectuur**: Een eenvoudig fully-connected neuraal netwerk met twee hidden layers (32 en 16 neurons, ReLU activatie) en een output layer met softmax activatie voor classificatie. Deze architectuur is licht genoeg om op een microcontroller te draaien.

- **Training**: Het model wordt getraind met Adam optimizer en sparse categorical crossentropy loss gedurende 50 epochs. Een deel van de trainingsdata (20%) wordt gebruikt voor validatie tijdens training.

- **TFLite conversie**: Het getrainde Keras model wordt geconverteerd naar TensorFlow Lite formaat met optimalisaties (`tf.lite.Optimize.DEFAULT`) voor kleinere modelgrootte en snellere inferentie op embedded hardware.

- **C array generatie**: Het TFLite model wordt ook geconverteerd naar een C header file (`gesture_model.h`) waar het model als byte array is opgeslagen. Dit maakt het mogelijk om het model direct in Arduino code te embedden zonder een apart bestand te moeten laden.

### gesture_classifier.ino

Dit is de Arduino code die het getrainde TensorFlow Lite model gebruikt om handgebaren te classificeren op een microcontroller. De code initialiseert de benodigde bibliotheken, laadt het model, verzamelt gegevens van de IMU-sensor, voert inferentie uit met het model en neemt acties op basis van de gedetecteerde gebaren.

**Belangrijkste delen van de code:**

- **TensorFlow Lite initialisatie**: De code includeert de Chirale TensorFlow Lite bibliotheek en laadt het model uit `gesture_model.h`. Een interpreter wordt aangemaakt met een tensor arena (memory buffer) voor het uitvoeren van inferentie.

- **IMU data verzameling**: De ingebouwde IMU sensor (BMI270/BMM150 op Nano 33 BLE Sense Rev2) wordt gebruikt om accelerometer en gyroscoop data te lezen. De code verzamelt een window van metingen (bijvoorbeeld 50-100 samples) om één gebaar te representeren.

- **Feature extraction op microcontroller**: Net zoals in het training script worden statistische features (mean, std, min, max) berekend voor elke as van de verzamelde sensor data. Deze features worden genormaliseerd met de opgeslagen `mean` en `std` waarden.

- **Inferentie**: De genormaliseerde features worden in de input tensor van het model geplaatst, waarna `interpreter->Invoke()` wordt aangeroepen om de voorspelling te maken. De output tensor bevat waarschijnlijkheden voor elke klasse.

- **Classificatie en actie**: Het gebaar met de hoogste waarschijnlijkheid (boven een bepaalde threshold) wordt geselecteerd. Op basis van het gedetecteerde gebaar (bv. "punch" of "circle") worden specifieke acties uitgevoerd zoals het sturen van een commando via Bluetooth of het aansturen van outputs.

⬅️ [Terug naar overzicht](../../README.md#bestandsstructuur)

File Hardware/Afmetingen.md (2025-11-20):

# Afmetingen 

## Mecanum wielen

Lengte: 8cm  
Breedte: 3,74cm  
Hoogte: 8cm

Poster

## Motors

Lengte: 7cm  
Breedte: 3,66cm  
Hoogte: 2,2cm

Motor

## Wielkoppeling en schroef

Wielkoppeling: 0,67cm  
Schroef: M2.5 x 0,3cm

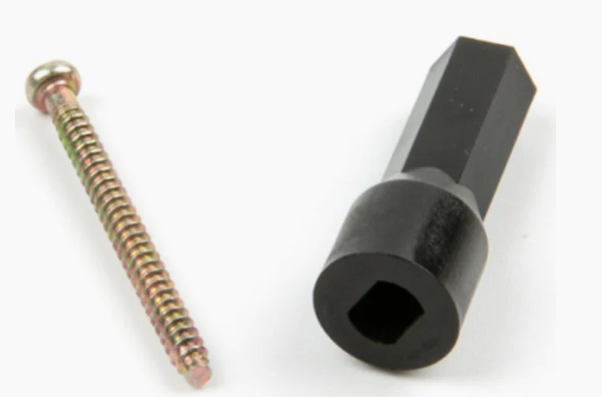
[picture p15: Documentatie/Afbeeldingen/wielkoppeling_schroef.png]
Wielkoppeling en schroef


## Motor driver

Lengte: 4,3cm   
Breedte: 4,3cm  
Hoogte: 2,7cm  

Driver

## Laser Receiver

zie afbeelding

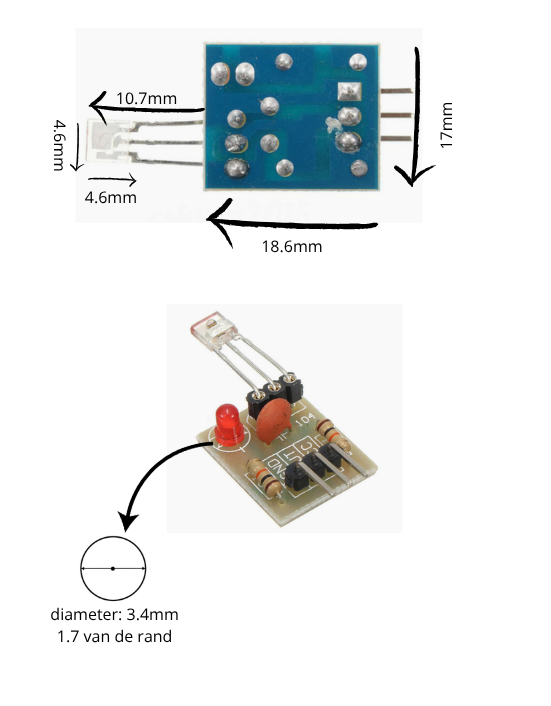
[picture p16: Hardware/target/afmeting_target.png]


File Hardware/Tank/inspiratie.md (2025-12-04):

## Inspiratie voor 3d model van de tank

[cabine + loop](https://cults3d.com/en/3d-model/game/interstellar-army-tank-cannon)

[Volledig model](https://cults3d.com/en/3d-model/game/british-armored-car-mk3-wwii-1-56-28mm)

[Grotere body, kleinere shietcabine, grotere loop](https://cults3d.com/en/3d-model/game/a-m-v-p-mk-iii-chinchilla-6x6-afv)

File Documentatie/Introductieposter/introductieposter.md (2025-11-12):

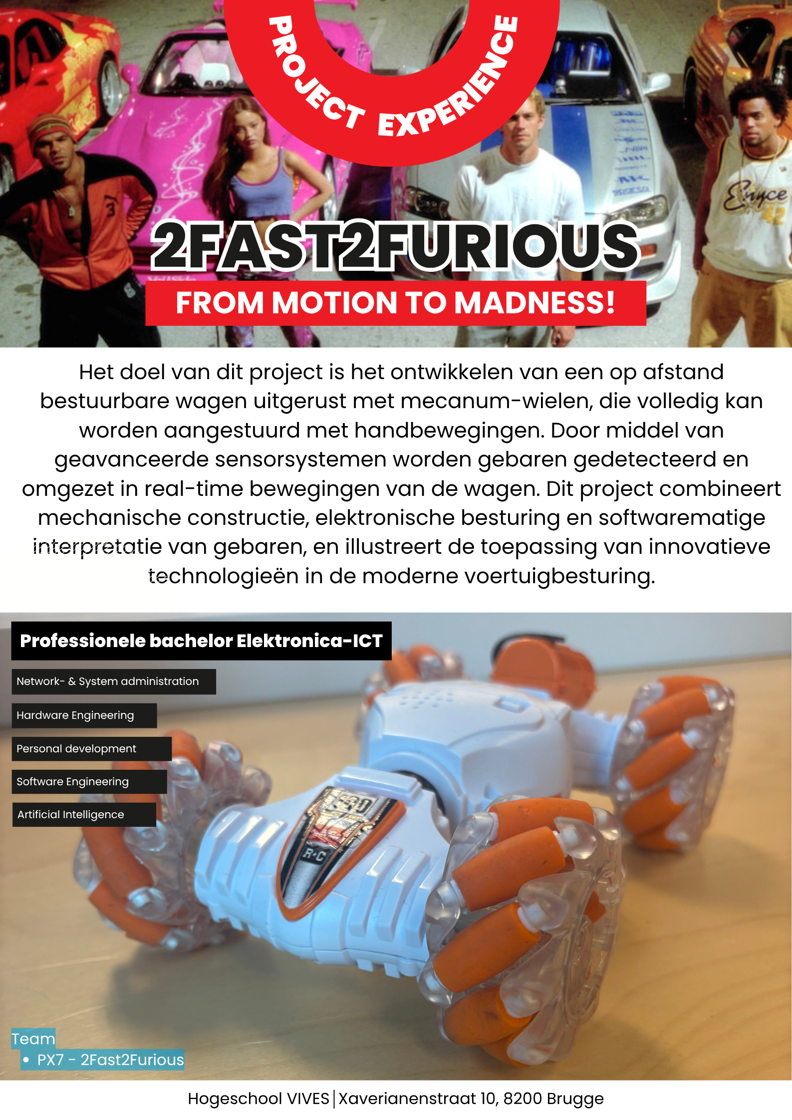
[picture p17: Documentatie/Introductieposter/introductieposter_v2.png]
Poster


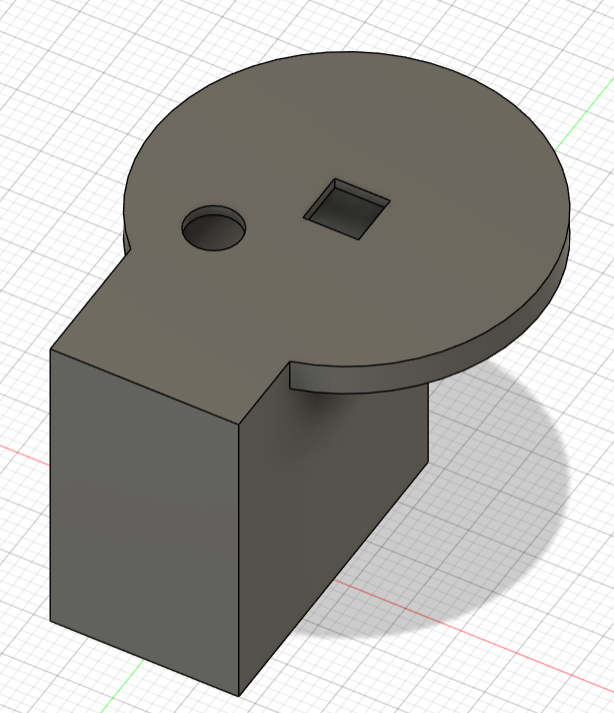
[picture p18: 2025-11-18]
Hardware/target/prototype_target.png

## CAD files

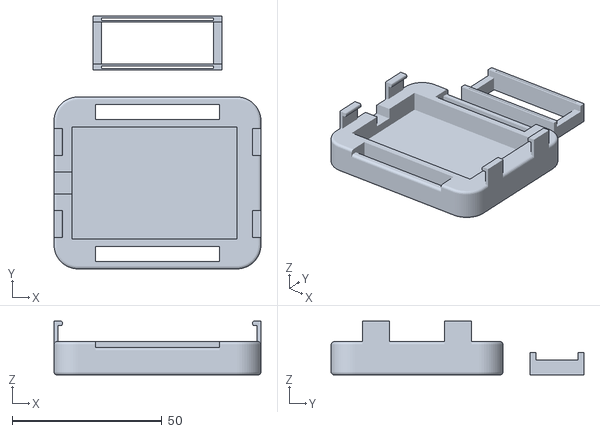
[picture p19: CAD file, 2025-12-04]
Hardware/HandController/STL_files/Hand Controller Housing RCC v14 - Top Only.stl
69.0 x 84.2 x 18.0

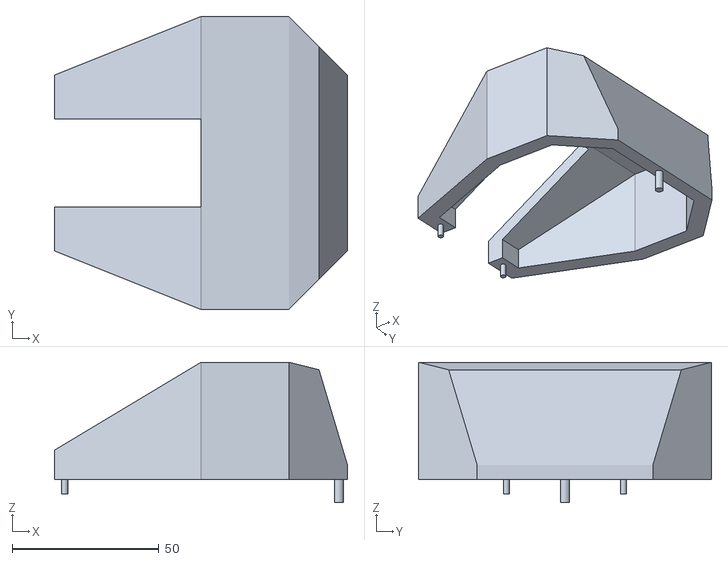
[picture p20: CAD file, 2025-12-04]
Hardware/Tank/STL_files/prototype_kopv3.stl
100.0 x 100.0 x 47.9

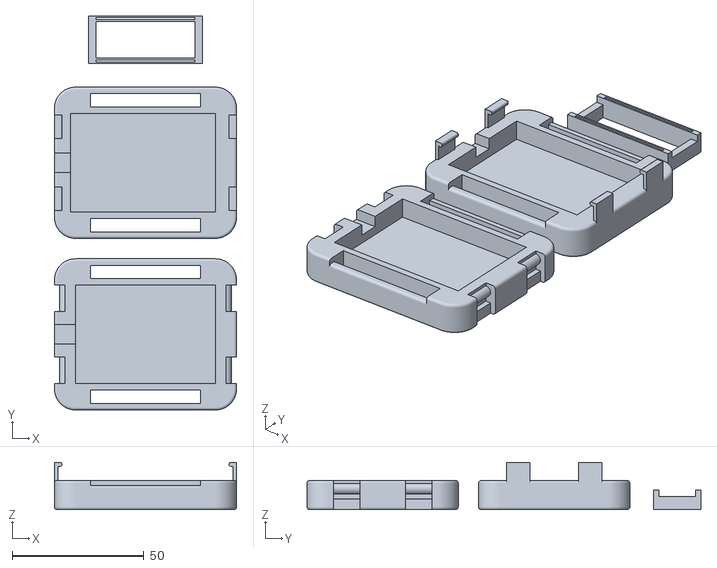
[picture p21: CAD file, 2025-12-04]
Hardware/HandController/STL_files/Hand Controller Housing RCC v14.stl
69.0 x 149.2 x 18.0

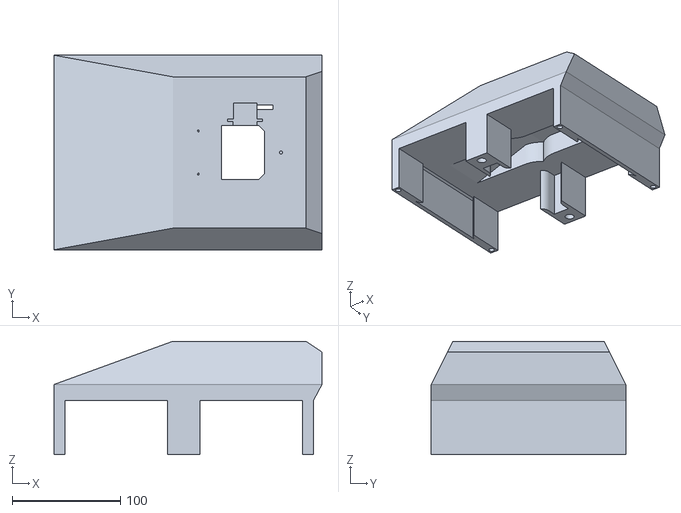
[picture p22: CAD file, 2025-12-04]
Hardware/Tank/STL_files/prototype_chassis2v3.stl
248.0 x 180.0 x 105.0

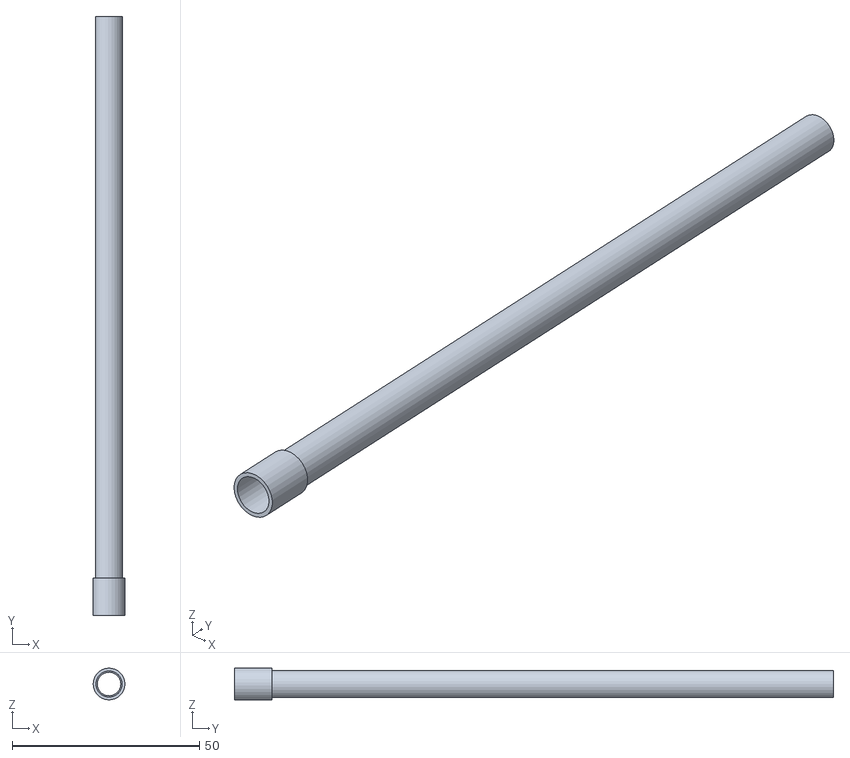
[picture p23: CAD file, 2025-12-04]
Hardware/Tank/STL_files/prototype_loopv1.stl
8.48 x 160.0 x 8.49

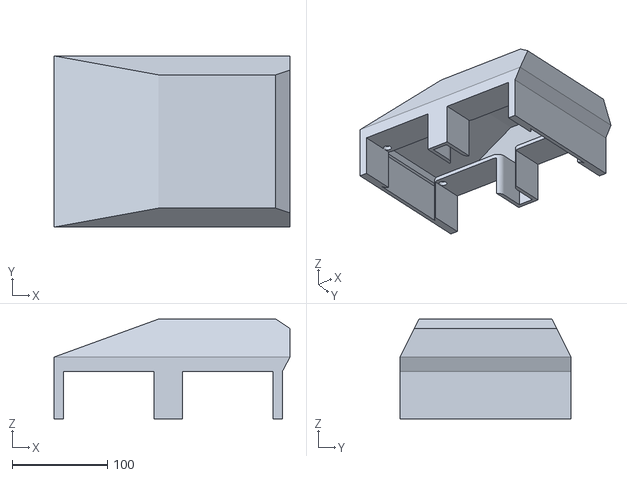
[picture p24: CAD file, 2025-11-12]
Hardware/Tank/STL_files/Prototype_chassis2_hull.stl
248.0 x 180.0 x 105.0

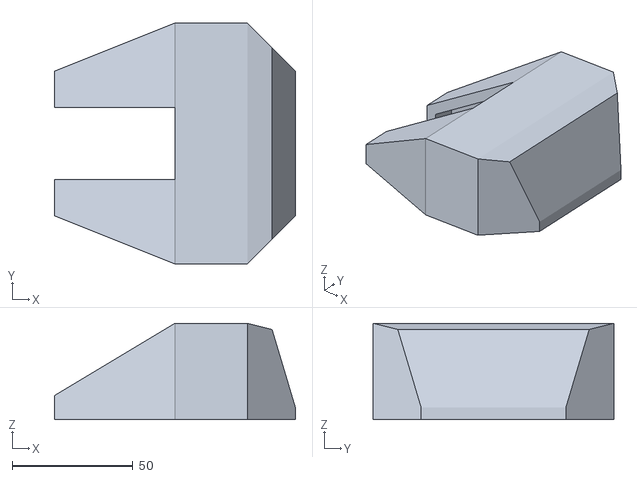
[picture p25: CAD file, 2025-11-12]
Hardware/Tank/STL_files/Prototype_chassis_turret.stl
100.0 x 100.0 x 40.0

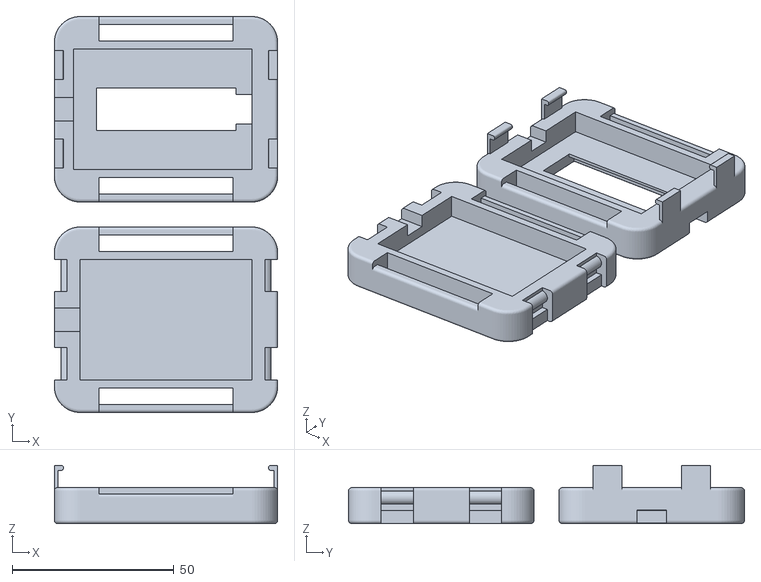
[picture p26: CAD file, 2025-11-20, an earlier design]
Hardware/HandController/STL_files/Hand Controller Housing RCC v12.stl
69.0 x 122.3 x 18.0

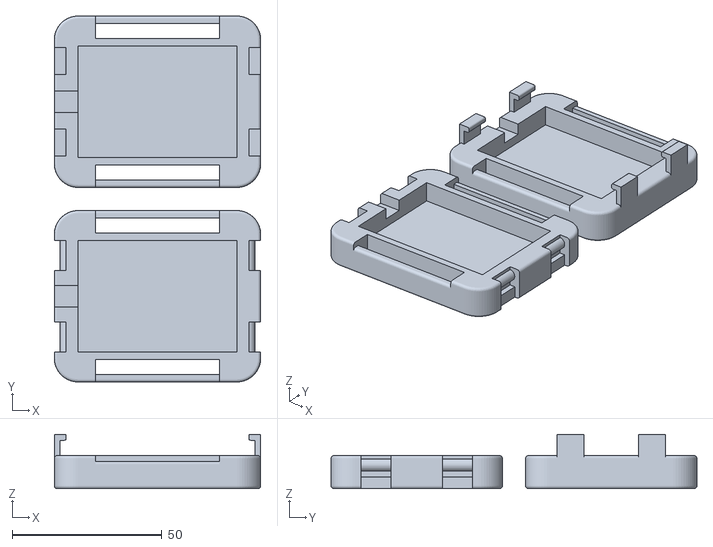
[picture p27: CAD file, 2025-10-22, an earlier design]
Hardware/HandController/STL_files/Hand Controller Housing RCC v6.stl
69.0 x 122.3 x 18.2

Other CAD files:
Hardware/HandController/STL_files/Hand Controller Housing RCC v10.stl
Hardware/HandController/STL_files/Hand Controller Housing RCC v8.stl

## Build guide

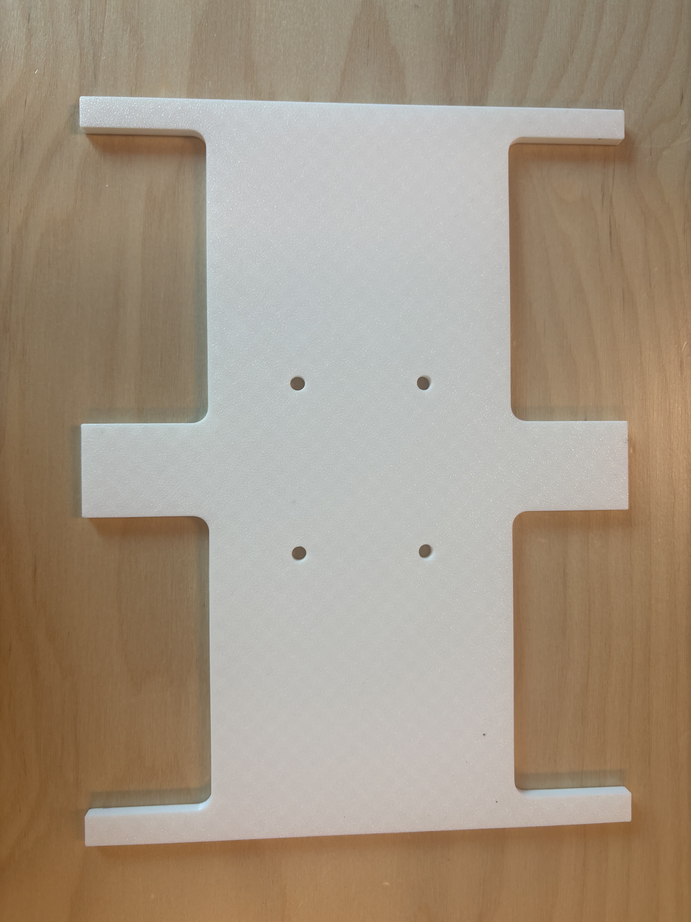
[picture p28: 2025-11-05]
Documentatie/Afbeeldingen/3d_print_v1.jpg

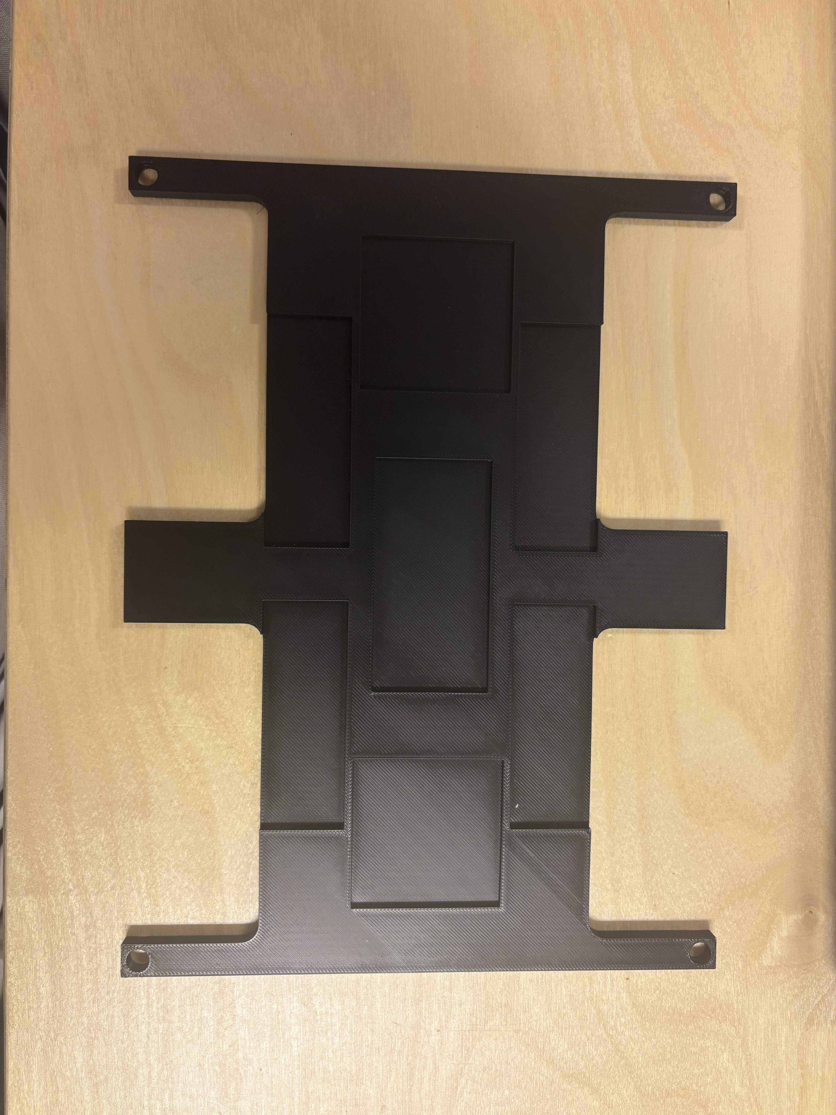
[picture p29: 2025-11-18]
Documentatie/Afbeeldingen/3d_print_v2.jpg

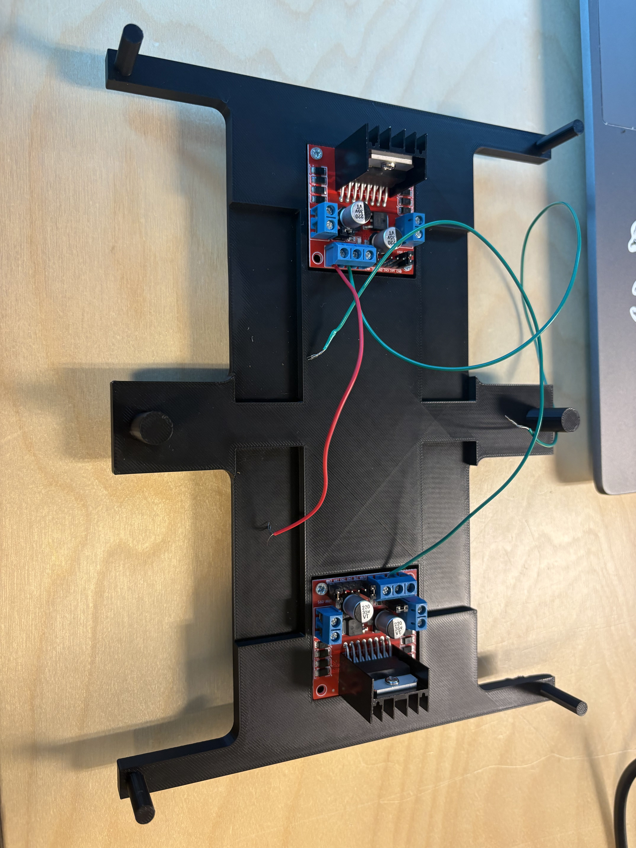
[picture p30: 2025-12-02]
Documentatie/Afbeeldingen/3d_print_v3.jpg

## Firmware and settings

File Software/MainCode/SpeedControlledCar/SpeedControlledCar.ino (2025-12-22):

#include <ArduinoBLE.h>
#include <Servo.h>

Servo myservo;
int pos = 50;       // startpositie servo
int servoState = 0; // 0 = stop, 1 = omhoog, -1 = omlaag
unsigned long lastServoMove = 0;

#define SPEED_PIN 4             // De enige overgebleven pin voor PWM (snelheidsregeling)
const int SNELHEID_MAX = 170;   // Maximale snelheid voor vooruit/achteruit/links/rechts
const int SNELHEID_DRAAI = 75; // Lagere snelheid voor draaiCW/draaiCCW

#define LazerPin 7

// Motor 1
#define M1_IN1 2
#define M1_IN2 3

// Motor 2
#define M2_IN1 5
#define M2_IN2 6

// Motor 3
#define M3_IN1 10
#define M3_IN2 11

// Motor 4
#define M4_IN1 13
#define M4_IN2 8

// BLE
BLEDevice peripheral;
BLECharacteristic commandChar;
bool connected = false;
String prevCommand = "";
bool tankmode = false;

void setMotorSpeed(int speed_value)
{
  analogWrite(SPEED_PIN, speed_value);
}

void motorVooruit(int in1, int in2)
{
  digitalWrite(in1, HIGH);
  digitalWrite(in2, LOW);
}

void motorAchteruit(int in1, int in2)
{
  digitalWrite(in1, LOW);
  digitalWrite(in2, HIGH);
}

void motorStop(int in1, int in2)
{
  digitalWrite(in1, LOW);
  digitalWrite(in2, LOW);
}

void vooruit()
{
  setMotorSpeed(SNELHEID_MAX);
  motorVooruit(M1_IN1, M1_IN2);
  motorVooruit(M2_IN1, M2_IN2);
  motorVooruit(M3_IN1, M3_IN2);
  motorVooruit(M4_IN1, M4_IN2);
}
void achteruit()
{
  setMotorSpeed(SNELHEID_MAX);
  motorAchteruit(M1_IN1, M1_IN2);
  motorAchteruit(M2_IN1, M2_IN2);
  motorAchteruit(M3_IN1, M3_IN2);
  motorAchteruit(M4_IN1, M4_IN2);
}
void links()
{
  setMotorSpeed(SNELHEID_MAX);
  motorAchteruit(M1_IN1, M1_IN2);
  motorVooruit(M2_IN1, M2_IN2);
  motorAchteruit(M3_IN1, M3_IN2);
  motorVooruit(M4_IN1, M4_IN2);
}
void rechts()
{
  setMotorSpeed(SNELHEID_MAX);
  motorVooruit(M1_IN1, M1_IN2);
  motorAchteruit(M2_IN1, M2_IN2);
  motorVooruit(M3_IN1, M3_IN2);
  motorAchteruit(M4_IN1, M4_IN2);
}

void draaiCW()
{
  setMotorSpeed(SNELHEID_DRAAI);
  motorAchteruit(M1_IN1, M1_IN2);
  motorVooruit(M2_IN1, M2_IN2);
  motorVooruit(M3_IN1, M3_IN2);
  motorAchteruit(M4_IN1, M4_IN2);
}

void frontleft(){
    setMotorSpeed(SNELHEID_MAX);
  motorVooruit(M2_IN1, M2_IN2);
  motorVooruit(M4_IN1, M4_IN2);
  }

void frontright(){
    setMotorSpeed(SNELHEID_MAX);
    motorVooruit(M1_IN1, M1_IN2);
    motorVooruit(M3_IN1, M3_IN2);
  
  }

void backleft(){
    setMotorSpeed(SNELHEID_MAX);
      motorAchteruit(M1_IN1, M1_IN2);
      motorAchteruit(M3_IN1, M3_IN2);
  }

void backright(){
    setMotorSpeed(SNELHEID_MAX);
    motorAchteruit(M2_IN1, M2_IN2);
    motorAchteruit(M4_IN1, M4_IN2);
  }

void ChangeState()
{
  tankmode = !tankmode;
}

void draaiCCW()
{
  setMotorSpeed(SNELHEID_DRAAI);
  motorVooruit(M1_IN1, M1_IN2);
  motorAchteruit(M2_IN1, M2_IN2);
  motorAchteruit(M3_IN1, M3_IN2);
  motorVooruit(M4_IN1, M4_IN2);
}

void stopAlles()
{
  setMotorSpeed(0);

  motorStop(M1_IN1, M1_IN2);
  motorStop(M2_IN1, M2_IN2);
  motorStop(M3_IN1, M3_IN2);
  motorStop(M4_IN1, M4_IN2);
}

void setup()
{
  Serial.begin(9600);

  myservo.attach(9);
  myservo.write(pos);

  pinMode(SPEED_PIN, OUTPUT);
  setMotorSpeed(0);

  // Motorpinnen
  pinMode(M1_IN1, OUTPUT);
  pinMode(M1_IN2, OUTPUT);
  pinMode(M2_IN1, OUTPUT);
  pinMode(M2_IN2, OUTPUT);
  pinMode(M3_IN1, OUTPUT);
  pinMode(M3_IN2, OUTPUT);
  pinMode(M4_IN1, OUTPUT);
  pinMode(M4_IN2, OUTPUT);

  pinMode(LazerPin, OUTPUT);

  // BLE setup
  if (!BLE.begin())
  {
    Serial.println("BLE start failed!");
    while (1)
      ;
  }

  Serial.println("Central start, zoekt naar NanoController...");
  BLE.scan();
}

void loop(){
  
  if (!connected)
    {
      stopAlles();
      BLEDevice found = BLE.available();
      Serial.println("Searching nano");

      if (found && found.localName() == "NanoClassifier")
      {
        Serial.println("Peripheral gevonden, verbinden...");
        BLE.stopScan();

        if (found.connect())
        {
          Serial.println("Verbonden!");
          peripheral = found;
          connected = true;

          if (peripheral.discoverAttributes())
          {
            commandChar = peripheral.characteristic("abcdef01-1234-5678-1234-56789abcdef0");
            if (commandChar)
            {
              commandChar.subscribe();
              Serial.println("Subscribed op command characteristic!");
            }
          }
        }
        else
        {
          Serial.println("Verbinding mislukt, opnieuw scannen...");
          BLE.scan();
        }
      }
    }

    if (connected && commandChar)
    {
      BLE.poll();

      if (commandChar.valueUpdated())
      {
        uint8_t buffer[20];
        int length = commandChar.readValue(buffer, sizeof(buffer));

        String cmd = "";
        if (length > 0)
        {
          buffer[length] = '\0';
          cmd = String((char *)buffer);
          Serial.print("Ontvangen commando: ");
          Serial.println(cmd);
        }

        if (cmd != prevCommand)
        {
          Serial.println(tankmode);
          prevCommand = cmd;

          if (cmd == "F" && tankmode == false)
          {
            vooruit();
            Serial.println("Vooruit");
          }
          else if (cmd == "C")
          {
            ChangeState();
            Serial.println("Change Mode");
          }
          else if (cmd == "B" && tankmode == false)
          {
            achteruit();
            Serial.println("Achteruit");
          }
          else if (cmd == "L" && tankmode == false)
          {
            links();
            Serial.println("Links");
          }
          else if (cmd == "R" && tankmode == false)
          {
            rechts();
            Serial.println("Rechts");
          }
          else if (cmd == "FL" && tankmode == false)
          {
            frontleft();
            Serial.println("Rechts");
          }
          else if (cmd == "FR" && tankmode == false)
          {
            frontright();
            Serial.println("Rechts");
          }
          else if (cmd == "BL" && tankmode == false)
          {
            backleft();
            Serial.println("Rechts");
          }
          else if (cmd == "BR" && tankmode == false)
          {
            backright();
            Serial.println("Rechts");
          }
          else if (cmd == "S")
          {
            Serial.println("Alles stoppen (ook servo)");
            stopAlles();
            servoState = 0;
          }
          else if (cmd == "F" && tankmode == true)
          {
            Serial.println("Servo omhoog");
            servoState = 1;
          }

          else if (cmd == "B" && tankmode == true)
          {
            Serial.println("Servo omlaag");
            servoState = -1;
          }
          else if (cmd == "L" && tankmode == true)
          {
            draaiCCW();
            Serial.println("Link in Tank Mode");
            }
          else if (cmd == "R" && tankmode == true)
          {
            draaiCW();
            Serial.println("Rechts in Tank Mode");
            }

          else if (cmd == "P")
          {
            Serial.println("Schieten");
            digitalWrite(LazerPin , HIGH);
            delay(3000);
            digitalWrite(LazerPin , LOW);
          }
          else
            stopAlles();
        }
      }

      if (!peripheral.connected())
      {
        Serial.println("Verbinding verbroken, opnieuw scannen...");
        connected = false;
        BLE.scan();
      }
    }
        //Serial.print("Servo Positie");
        //Serial.println(pos);
    if (servoState != 0)
    {
      unsigned long now = millis();

      if (now - lastServoMove >= 20)
      {
        lastServoMove = now;

        if (servoState == 1)
        {
          if (pos < 75)
          {
            pos++;
            myservo.write(pos);
            if (pos >= 75) servoState = 0;
          }
          else
          {
            servoState = 0;
          }
        }

        else if (servoState == -1)
        {
          if (pos > 25)
          {
            pos--;
            myservo.write(pos);
            if (pos <= 25) servoState = 0;
          }
          else
          {
            servoState = 0;
          }
        }
      }
    }
  // test voor alle modes na elkaar
  /*
  delay(5000);
  vooruit();
  Serial.println("Vooruit");
  delay(2000);

  stopAlles();
  delay(1000);

  achteruit();
  Serial.println("Achteruit");
  delay(2000);

  stopAlles();
  delay(1000);

  links();
  Serial.println("Links");
  delay(2000);

  stopAlles();
  delay(1000);

  rechts();
  Serial.println("Rechts");
  delay(2000);

  stopAlles();
  delay(1000);

  draaiCCW();
  Serial.println("Links in Tank Mode");
  delay(2000);

  stopAlles();
  delay(1000);

  draaiCW();
  Serial.println("Rechts in Tank Mode");
  delay(2000);

  stopAlles();*/
}

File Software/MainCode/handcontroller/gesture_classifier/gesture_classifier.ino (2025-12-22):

// TensorFlow Lite Micro gesture classifier
// Uses Arduino Nano 33 BLE Rev.2 with BMI270/BMM150 IMU

#define DISABLE_BLE 0
#include <Arduino_BMI270_BMM150.h>
#if !DISABLE_BLE
#include <ArduinoBLE.h>
#endif
#include <Chirale_TensorFlowLite.h>
#include "tensorflow/lite/micro/all_ops_resolver.h"
#include "tensorflow/lite/micro/micro_interpreter.h"
#include "tensorflow/lite/micro/micro_log.h"
#include "tensorflow/lite/micro/system_setup.h"
#include "tensorflow/lite/schema/schema_generated.h"

#include "gesture_model.h"

// Settings
// NOTE: NUM_SAMPLES required to be 200 for compatibility with data collection
const int NUM_SAMPLES = 200; // Number of samples per gesture
const int NUM_AXES = 6;      // 3 accel + 3 gyro
const int NUM_FEATURES = 24; // 4 stats per axis (mean, std, min, max)
const int NUM_CLASSES = 3;

// Labels matching training order
const char *GESTURES[] = {"Punch", "circle", "idle"};

// TFLite globals
const tflite::Model *model = nullptr;
tflite::MicroInterpreter *interpreter = nullptr;
TfLiteTensor *input = nullptr;
TfLiteTensor *output = nullptr;

// BLE service and characteristic (same UUIDs as Hand.ino)
#if !DISABLE_BLE
BLEService controlService("12345678-1234-5678-1234-56789abcdef0");
BLEStringCharacteristic commandCharacteristic("abcdef01-1234-5678-1234-56789abcdef0", BLERead | BLENotify, 20);
bool deviceConnected = false;
bool bleInitialized = false;
String prevCommand = "";
#else
// Stubs when BLE is disabled
bool deviceConnected = false;
bool bleInitialized = false;
String prevCommand = "";
#endif

constexpr int kTensorArenaSize = 12 * 1024;
alignas(16) uint8_t tensor_arena[kTensorArenaSize];

// Buffers for sensor data (compact int16 to save RAM)
// accel stored as milli-g (a * 1000), gyro stored as centi-deg/s (g * 100)
int16_t sample_buffer[NUM_SAMPLES][NUM_AXES];
int samples_read = 0;

// Non-blocking sampling state
bool samplingActive = false;
unsigned long nextSampleMs = 0;
const unsigned long sampleIntervalMs = 10; // ms between samples
unsigned long nextCycleMs = 0;             // cooldown between gesture cycles
const unsigned long cycleCooldownMs = 500; // wait after inference before next sampling run

// Logging control: how many xi/yi samples to print per full buffer
const int LOG_SAMPLES = 12;                                              // number of samples to print per cycle (approx)
const int LOG_INTERVAL = (NUM_SAMPLES + LOG_SAMPLES - 1) / LOG_SAMPLES; // ceil division

// Track whether the last detected gesture was idle (index 2 in GESTURES)
bool lastDetectedIsIdle = true;

unsigned long lastSampleTime = 0;
const unsigned long sampleStallTimeoutMs = 2000; // reset if no samples in 2s

// Preprocessing params (from model_params.npz)
// Mark as const so these tables are stored in flash instead of RAM
const float feature_mean[NUM_FEATURES] = {
    -0.0086, 1.5866, -3.8708, 3.5721, 0.0230, 1.8307,
    -5.0121, 5.2136, 9.5987, 1.3837, 5.2731, 13.6194,
    -0.8927, 23.3695, -61.3211, 63.1349, 0.3478, 26.2515,
    -66.5243, 70.0886, 0.3911, 26.0975, -64.4345, 67.9083};
const float feature_std[NUM_FEATURES] = {
    0.5079, 1.3467, 3.2853, 3.2297, 0.5279, 1.2310,
    3.3168, 3.2202, 0.3231, 0.8846, 3.2046, 2.4673,
    5.0700, 24.5948, 52.3558, 52.8383, 3.6086, 19.1646,
    50.0784, 48.7146, 1.7509, 20.9778, 51.2285, 47.8745};

void setup()
{
  Serial.begin(115200);
  

  // Initialize IMU
  if (!IMU.begin())
  {
    Serial.println("ERROR: IMU initialization failed!");
    while (1)
      ;
  }

  Serial.println("IMU initialized");
  Serial.print("Acceleration sample rate: ");
  Serial.print(IMU.accelerationSampleRate());
  Serial.println(" Hz");

  // Initialize BLE (can be disabled at compile time to isolate issues)
#if !DISABLE_BLE
  if (!BLE.begin())
  {
    Serial.println("ERROR: BLE start failed!");
    // don't block here; continue without BLE
  }
  else
  {
    bleInitialized = true;
    BLE.setLocalName("NanoClassifier");
    BLE.setAdvertisedService(controlService);
    controlService.addCharacteristic(commandCharacteristic);
    BLE.addService(controlService);
    BLE.advertise();
    Serial.println("BLE initialized and advertising");
  }
#else
  Serial.println("BLE disabled at compile time");
#endif

  // Load TFLite model
  model = tflite::GetModel(gesture_model);
  if (model->version() != TFLITE_SCHEMA_VERSION)
  {
    Serial.println("ERROR: Model schema mismatch!");
    while (1)
      ;
  }

  // Initialize TFLite interpreter
  static tflite::AllOpsResolver resolver;
  static tflite::MicroInterpreter static_interpreter(
      model, resolver, tensor_arena, kTensorArenaSize);
  interpreter = &static_interpreter;

  // Allocate tensors
  TfLiteStatus allocate_status = interpreter->AllocateTensors();
  if (allocate_status != kTfLiteOk)
  {
    Serial.println("ERROR: AllocateTensors() failed");
    while (1)
      ;
  }

  // Get input/output tensors
  input = interpreter->input(0);
  output = interpreter->output(0);

  Serial.println("TFLite model loaded successfully");
  Serial.println("Gesture classifier ready!");
  Serial.println("Perform a gesture to classify...\n");
}

void extractFeatures(float features[NUM_FEATURES])
{
  // Extract statistical features per axis.
  // Convert stored int16_t samples back to the units expected by the model:
  //  - accel: stored as milli-g -> convert to m/s^2 via *0.001*9.80665
  //  - gyro: stored as centi-deg/s -> convert to deg/s via *0.01
  const float ACCEL_SCALE = 0.001f * 9.80665f; // milli-g -> m/s^2
  const float GYRO_SCALE = 0.01f;              // centi-deg/s -> deg/s

  for (int axis = 0; axis < NUM_AXES; axis++)
  {
    float sum = 0.0f, sum_sq = 0.0f;
    // Initialize min/max from first sample converted
    float first_val;
    if (axis < 3)
    {
      first_val = sample_buffer[0][axis] * ACCEL_SCALE;
    }
    else
    {
      first_val = sample_buffer[0][axis] * GYRO_SCALE;
    }
    float min_val = first_val;
    float max_val = first_val;

    // Calculate sum, min, max over converted values
    for (int i = 0; i < NUM_SAMPLES; i++)
    {
      float val;
      if (axis < 3)
      {
        val = sample_buffer[i][axis] * ACCEL_SCALE;
      }
      else
      {
        val = sample_buffer[i][axis] * GYRO_SCALE;
      }
      sum += val;
      sum_sq += val * val;
      if (val < min_val)
        min_val = val;
      if (val > max_val)
        max_val = val;
    }

    // Calculate mean and std
    float mean = sum / NUM_SAMPLES;
    float variance = (sum_sq / NUM_SAMPLES) - (mean * mean);
    float std_dev = sqrt(variance > 0 ? variance : 0);

    // Store features: mean, std, min, max for each axis
    int base_idx = axis * 4;
    features[base_idx + 0] = mean;
    features[base_idx + 1] = std_dev;
    features[base_idx + 2] = min_val;
    features[base_idx + 3] = max_val;
  }
}

void normalizeFeatures(float features[NUM_FEATURES])
{
  for (int i = 0; i < NUM_FEATURES; i++)
  {
    features[i] = (features[i] - feature_mean[i]) / feature_std[i];
  }
}
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

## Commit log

2025-09-25 added gyroscope test
2025-09-25 Added bom tabel
2025-10-02 Bluetooth on arduino nano 33
2025-10-08 Edited BOM and added info of components
2025-10-09 Edited BOM
2025-10-22 .stl files hand controller
    [Hand Controller Housing v6.stl]
2025-10-23 Updated stl.files
    [Hand Controller Housing RCC v8.stl, Hand Controller Housing v6.stl]
2025-11-03 wat moet de auto kunnen
2025-11-03 richtingen toegevoegt aan motor test code
2025-11-06 Updated Hand Controller Model + Deprecated Documentation
    [Hand Controller Housing RCC v6.stl, Hand Controller Housing RCC v9.stl]
2025-11-06 added stl files
    [Prototype_chassis2_hull.stl, Prototype_chassis_turret.stl]
2025-11-10 Update Hand Controller Housing .stl
    [Hand Controller Housing RCC v10.stl, Hand Controller Housing RCC v9.stl]
2025-11-13 schema arduino flip
2025-11-18 Added new self trained ai model
    [dataset.csv]
2025-11-20 Update Hand Controller .stls + circuit
    [Hand Controller Housing RCC v12.stl]
2025-11-24 servo added to main code
2025-11-24 snelheid motoren
2025-11-27 servo state
2025-11-27 trained new model
    [dataset.csv]
2025-11-27 update hand controller model
    [Hand Controller Housing RCC v13.stl]
2025-12-04 update hand controller housing stl files
    [Hand Controller Housing RCC v13.stl, Hand Controller Housing RCC v14.stl]
2025-12-04 GitHub opkuis
    [Hand Controller Housing RCC v10.stl, Hand Controller Housing RCC v12.stl, Hand Controller Housing RCC v14.stl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]
2025-12-04 removed some files
    [dataset.csv]
2025-12-04 Update BOM
2025-12-04 readme and failsafe for disconnect
    [SpeedControlledCar.ino, auto.ino]
2025-12-04 af te printen folder met stls
    [Hand Controller Housing RCC v14 - Top Only.stl, prototype_loopv1.stl]
2025-12-04 removed af te printen folder, direct links to stl files
    [Hand Controller Housing RCC v14 - Top Only.stl, prototype_loopv1.stl]
2025-12-04 Update task list to mark laser transmitter as complete
2025-12-04 added schema laser
2025-12-04 added components of laser turret circuit
2025-12-11 Added handleiding
    [Hand Controller Housing RCC v10.stl, Hand Controller Housing RCC v12.stl, Hand Controller Housing RCC v14 - Top Only.stl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]
2025-12-11 fixed code and servo
    [SpeedControlledCar.ino, gesture_classifier.ino]
